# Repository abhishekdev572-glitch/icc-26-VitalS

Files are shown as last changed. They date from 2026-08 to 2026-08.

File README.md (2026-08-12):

# VitalSense Pressure Ulcer Prevention System

## Overview

VitalSense is an end-to-end pressure ulcer prevention system for bedridden patients. It combines an 8-sensor force-sensing resistor (FSR) array, inertial measurement unit (IMU), on-device machine learning inference, and real-time caregiver dashboards to continuously monitor posture, pressure distribution, and tissue injury risk across four anatomical zones (head, shoulders, hips, heels).

## System Architecture

```mermaid
graph TD
    subgraph Bed_Unit [Bedside Hardware]
        FSR[8× FSR Sensors\n74HC4051 MUX]
        ESP[ESP32-C3 Gateway\nBLE Peripheral + UDP Broadcaster]
        EFR[EFR32xG26 Node\nIMU + ML Inference + BLE Central]
    end

    subgraph Dashboards [Caregiver Interfaces]
        MOBILE[Flutter Mobile App\nUDP Listener]
        WEB[Web Kiosk Dashboard\nGTK4 + WebKit2]
    end

    FSR -->|ADC 0-4095| ESP
    ESP <-->|BLE GATT\nCommands 0x01/0x02/0x03| EFR
    EFR -->|IMU 60 Hz| EFR
    EFR -->|ML Risk 0-100| ESP
    ESP -->|UDP Broadcast\nPort 5005\nJSON v1| MOBILE
    ESP -->|UDP Broadcast\nPort 5005\nJSON v1| WEB

    style FSR fill:#e8f0fe,stroke:#1a73e8,stroke-width:2px,color:#1a73e8
    style ESP fill:#e6f4ea,stroke:#1e8e3e,stroke-width:2px,color:#1e8e3e
    style EFR fill:#fff3cd,stroke:#e67e22,stroke-width:2px,color:#e67e22
    style MOBILE fill:#fce4ec,stroke:#c2185b,stroke-width:2px,color:#c2185b
    style WEB fill:#f3e5f5,stroke:#7b1fa2,stroke-width:2px,color:#7b1fa2
```

## Hardware Requirements

| Component | Part Number | Quantity | Role |
|---|---|---|---|
| ESP32-C3 Development Board | ESP32-C3-DevKitM-1 / SuperMini | 1 | FSR acquisition, BLE peripheral, UDP broadcaster |
| EFR32xG26 Development Kit | BRD2608A (xG26) | 1 | IMU posture detection, ML inference, BLE central |
| Force Sensing Resistors | Interlink FSR 402 / equivalent | 8 | Pressure sensing at anatomical zones |
| Analog Multiplexer | 74HC4051 / CD4051 | 1 | 8-channel to single ADC |
| Inertial Measurement Unit | ICM-40627 (on xG26 board) | 1 | 6-axis motion, posture classification |
| Power Supply | 5V 2A USB-C | 2 | ESP32-C3 and EFR32xG26 power |

## Component Breakdown

| Component | Location | Technology Stack | Primary Responsibility |
|---|---|---|---|
| ESP32-C3 Firmware | `projects/Pipeline/ESP32 firmware/` | Arduino Core, NimBLE-Arduino 2.3.7 | 8-channel FSR acquisition via MUX, BLE GATT server, plate averaging, UDP JSON broadcast (1 Hz) |
| EFR32xG26 Firmware | `projects/Pipeline/EFR xG26 firmware/bt_imu_mode/` | C, Silicon Labs Gecko SDK 2026.6, TFLite Micro | IMU calibration (CENTER/LEFT/RIGHT), posture tracking at 60 Hz, BLE central connection to ESP32, ML inference, risk/state transmission |
| ML Model | `projects/Pipeline/model/` | PyTorch, ONNX, TensorFlow Lite | 380-parameter MLP (12→16→8→4), risk prediction 0-100 per zone, deployed as TFLite on EFR32 |
| Synthetic Dataset Kit | `projects/Pipeline/Synthetic dataset kit/` | Python, Pandas, PyTorch, scikit-learn | 60,000-sample synthetic dataset generation, teacher risk function, model training pipeline, ONNX/TFLite export |
| Mobile App | `projects/vitalsense-app/` | Flutter 3.x, Dart 3.x | UDP listener (port 5005), real-time gauges, posture duration, risk visualization, diagnostics panel |
| Web Dashboard | `projects/vitalsense-dashboard/` | Python 3.10+, GTK4, WebKit2GTK, React (JSX) | Kiosk-mode UDP receiver, HTTP frontend (port 8080), WebView display, SSE live updates |

## Communication Protocols

### BLE GATT (EFR32xG26 ↔ ESP32-C3)

| Parameter | Value |
|---|---|
| Target Device Name | `VitalSense-ESP32C3` |
| Service UUID | `7a0a0001-5b8a-4f4c-9d1d-8b4e3d7a1000` |
| RX Characteristic (EFR→ESP) | `7a0a0002-5b8a-4f4c-9d1d-8b4e3d7a1000` (Write w/ Response) |
| TX Characteristic (ESP→EFR) | `7a0a0003-5b8a-4f4c-9d1d-8b4e3d7a1000` (Notify) |

**Commands (EFR32 → ESP32):**

| Command | Payload | Description |
|---|---|---|
| `0x01` | (none) | Request fresh 8-FSR scan |
| `0x02` | `bodyId (1-4), risk (0-100), avoidFlag (0/1)` | ML risk update per body part |
| `0x03` | `pos, durationSec, riskValid, zoneId, score, level` | Posture + duration + summary state |

**Response (ESP32 → EFR32):**

| Byte | Value |
|---|---|
| `[0]` | `0x81` |
| `[1]` | `0x08` (sensor count) |
| `[2..17]` | 8 × `uint16_t` little-endian FSR values (ADC 0-4095) |

**Body IDs:**

| ID | Anatomical Zone |
|----|---|
| 1 | Head |
| 2 | Shoulders |
| 3 | Hips |
| 4 | Heels |

**Risk Levels:**

| Level | Value |
|---|---|
| LOW | 0 |
| MEDIUM | 1 |
| HIGH | 2 |

### UDP Broadcast (ESP32-C3 → Dashboards)

| Parameter | Value |
|---|---|
| Port | 5005 (broadcast to subnet) |
| Interval | 1000 ms |
| Format | JSON (manual `snprintf`, no ArduinoJson) |
| Protocol Version | 1 |

**Sample Payload:**

```json
{
  "protocol": 1,
  "deviceId": "VS-BED-001",
  "bed": 1,
  "position": "CENTER",
  "positionDuration": 45,
  "plates": {"head": 2048, "shoulders": 1892, "hips": 3120, "heels": 1567},
  "fsr": [2010, 2086, 1845, 1939, 3088, 3152, 1521, 1613],
  "riskValid": true,
  "risk": {"head": 12, "shoulders": 8, "hips": 45, "heels": 3},
  "highestRisk": {"zone": "HIPS", "score": 45, "level": "MEDIUM"},
  "avoidReturn": {"head": 0, "shoulders": 0, "hips": 0, "heels": 0},
  "uptime": 1234
}
```

**Field Reference:**

| Field | Type | Description |
|---|---|---|
| `protocol` | integer | Protocol version (1) |
| `deviceId` | string | Unique bed identifier |
| `bed` | integer | Bed number |
| `position` | string | `CENTER`, `LEFT`, `RIGHT`, `UNKNOWN` |
| `positionDuration` | integer | Uninterrupted seconds in current posture |
| `plates` | object | 4 averaged plate ADC values (0-4095) |
| `fsr` | array[8] | 8 raw FSR ADC values (0-4095) |
| `riskValid` | boolean | True after EFR32 threshold + all 4 risk packets |
| `risk` | object | Per-zone risk 0-100 (or -1 if invalid) |
| `highestRisk` | object | Zone with max risk + score + level |
| `avoidReturn` | object | Per-zone avoid flags (0/1) |
| `uptime` | integer | ESP32 uptime in seconds |

## Build & Setup Instructions

### ESP32-C3 Firmware

**Prerequisites:**
- Arduino IDE 2.x or VS Code + PlatformIO
- ESP32 Arduino Core 3.x
- NimBLE-Arduino library (Library Manager → "NimBLE-Arduino")

**Arduino IDE:**
1. Add board URL: `https://raw.githubusercontent.com/espressif/arduino-esp32/gh-pages/package_esp32_index.json`
2. Tools → Board → ESP32 Arduino → ESP32C3 Dev Module
3. Install library: Sketch → Include Library → Manage Libraries → NimBLE-Arduino
4. Open `VitalSense_ESP32.ino`
5. Configure WiFi credentials at top of file
6. Select port → Upload

**PlatformIO (`platformio.ini`):**
```ini
[env:esp32c3]
platform = espressif32
board = esp32c3-devkitm-1
framework = arduino
lib_deps = h2zero/NimBLE-Arduino@^2.3.7
monitor_speed = 115200
```

### EFR32xG26 Firmware

**Prerequisites:**
- Simplicity Studio 5 (v5.2+)
- Gecko SDK 2026.6.0
- BRD2608A (xG26 Dev Kit)

**Steps:**
1. File → Import → Silicon Labs → Project from SLCP
2. Select `bt_imu_mode.slcp`
3. Connect BRD2608A (power switch → AEM position)
4. Build (hammer icon)
5. Flash (debug icon)

**Post-Build (OTA DFU):**
```bash
commander gbl create output.gbl --app output.s37
```

**Pre-built Firmware:** Available at `bt_imu_mode/firmware file/bt_imu_mode.s37`

### ML Model Pipeline

**Prerequisites:**
```bash
pip install numpy pandas torch scikit-learn onnx onnxruntime tf2onnx
```

**Generate Dataset + Train:**
```bash
cd "projects/Pipeline/Synthetic dataset kit"
python build_pressure_risk_dataset.py
```

**Outputs:**
- `synthetic_pressure_ulcer_risk_dataset.csv` (60,000 rows)
- `pressure_risk_mlp.pt` (PyTorch state dict)
- `pressure_risk_model_metadata.json` (full provenance)

**Convert to TFLite (for EFR32):**
```bash
# Option 1: tf2onnx + tflite_convert
python -m tf2onnx.convert --input pressure_risk_mlp.onnx --output pressure_risk_mlp_tf.onnx
tflite_convert --output_file pressure_risk_mlp.tflite --input_file pressure_risk_mlp_tf.onnx

# Option 2: Silicon Labs AI/ML SDK (recommended)
# In Simplicity Studio: add "ML Model" component → select .tflite → auto-generates C++ wrapper
```

### Mobile App (Flutter)

**Prerequisites:**
- Flutter SDK >= 3.0.0
- Android SDK (for APK build)

```bash
cd projects/vitalsense-app
flutter pub get
flutter analyze
flutter run
```

**Production APK:**
```bash
flutter build apk --release
# Output: build/app/outputs/flutter-apk/app-release.apk
```

### Web Dashboard

```bash
cd projects/vitalsense-dashboard
python3 -m venv venv
source venv/bin/activate
# Ubuntu/Debian: sudo apt install python3-gi python3-gi-cairo gir1.2-gtk-4.0 gir1.2-webkit2-4.1
python app.py
```

## ADC Calibration & Model Specifications

### ADC Calibration (q05 / q95 per Zone)

Used for ADC → load normalization: `load = clip((adc - q05) / (q95 - q05), 0, 1)`

| Zone | q05 (Low Load) | q95 (High Load) |
|---|---|---|
| Head | 3119 | 3932 |
| Shoulders | 3537 | 3994 |
| Hips | 3007 | 3909 |
| Heels | 3222 | 4021 |

### Model Architecture

```
Input (12) → Linear(16) → ReLU → Linear(8) → ReLU → Linear(4) → Sigmoid
```

| Layer | Size |
|---|---|
| Input | 12 |
| Hidden 1 | 16 |
| Hidden 2 | 8 |
| Output | 4 |

**Parameters:** 380

### Model Inputs (12 Features, Fixed Order)

| Index | Feature | Description | Range |
|---|---|---|---|
| 0 | `position_CENTER` | One-hot posture | {0, 1} |
| 1 | `position_LEFT` | One-hot posture | {0, 1} |
| 2 | `position_RIGHT` | One-hot posture | {0, 1} |
| 3 | `log_duration_normalized` | `log1p(duration_sec) / log1p(7200)` | [0, 1] |
| 4 | `head_load` | Normalized pressure (ADC→load) | [0, 1] |
| 5 | `shoulders_load` | Normalized pressure | [0, 1] |
| 6 | `hips_load` | Normalized pressure | [0, 1] |
| 7 | `heels_load` | Normalized pressure | [0, 1] |
| 8 | `head_exposure_scaled` | Cumulative exposure (pressure × time) | [0, 1] |
| 9 | `shoulders_exposure_scaled` | Cumulative exposure | [0, 1] |
| 10 | `hips_exposure_scaled` | Cumulative exposure | [0, 1] |
| 11 | `heels_exposure_scaled` | Cumulative exposure | [0, 1] |

### Model Outputs (4)

| Index | Output | Description | Range |
|---|---|---|---|
| 0 | `head_risk_score_0_to_1` | Risk probability | [0, 1] |
| 1 | `shoulders_risk_score_0_to_1` | Risk probability | [0, 1] |
| 2 | `hips_risk_score_0_to_1` | Risk probability | [0, 1] |
| 3 | `heels_risk_score_0_to_1` | Risk probability | [0, 1] |

**Firmware scales to 0–100** for BLE transmission.

### Teacher Risk Function (Synthetic Labels)

```python
effective = clip((load - relief_floor) / (1.0 - relief_floor), 0, 1)
dose = effective^pressure_exponent * duration_sec / reference_duration_seconds
risk = 100 * (1 - exp(-risk_gain * dose))
```

| Parameter | Value |
|---|---|
| `reference_duration_seconds` | 7200 (2 hours) |
| `relief_floor` | 0.10 |
| `pressure_exponent` | 1.50 |
| `risk_gain` | 1.50 |
| `low_medium_threshold` | 35.0 |
| `medium_high_threshold` | 70.0 |

### Performance Metrics (Test Set: 12,000 rows, 24 subjects)

| Metric | Value |
|---|---|
| MAE (risk points 0–100) | 1.88 |
| RMSE (risk points 0–100) | 2.75 |
| Max Abs Error | 21.19 |
| Highest-risk body part accuracy | 90.2% |
| Highest-risk level (LOW/MED/HIGH) accuracy | 97.0% |

## Third-Party Libraries

| Library | Version | Location | Purpose |
|---|---|---|---|
| TensorFlow Lite Micro (TFLM) | 2.x | `projects/Pipeline/EFR xG26 firmware/bt_imu_mode/autogen/ml/third_party/tflm/` | On-device ML inference engine |
| FlatBuffers | 23.x | `.../flatbuffers/` | TFLite model serialization format |
| gemmlowp | — | `.../gemmlowp/` | Low-precision matrix multiplication for TFLM |
| ruy | — | `.../ruy/` | Matrix multiplication library for TFLM |
| NimBLE-Arduino | 2.3.7 | ESP32 firmware (PlatformIO/lib_deps) | Lightweight BLE stack for ESP32-C3 |

## Project Structure

```
icc-26-VitalS/
├── README.md                           # This file
├── LICENSE.md
├── .github/
│   ├── basic-ruleset.json
│   ├── CODEOWNERS
│   ├── CONTRIBUTING.md
│   └── workflows/
├── projects/
│   ├── README.md                       # Projects index
│   ├── vitalsense-app/                 # Flutter mobile app
│   │   ├── lib/
│   │   ├── android/
│   │   ├── pubspec.yaml
│   │   ├── README.md
│   │   └── VitalSense_Dashboard_Integration_Protocol_v1.md
│   ├── vitalsense-dashboard/           # Python GTK/WebKit kiosk
│   │   ├── app.py
│   │   ├── config.json
│   │   ├── backend/
│   │   ├── frontend/
│   │   ├── core/
│   │   ├── ui/
│   │   ├── assets/
│   │   └── README.md
│   └── Pipeline/
│       ├── ESP32 firmware/
│       │   ├── VitalSense_ESP32.ino
│       │   └── README.md
│       ├── EFR xG26 firmware/
│       │   ├── bt_imu_mode/            # Complete source project
│       │   │   ├── app.c / app.h
│       │   │   ├── main.c
│       │   │   ├── pressure_risk_ml_xg26.h/.cpp
│       │   │   ├── bt_imu_mode.slcp
│       │   │   ├── config/tflite/pressure_risk_mlp.tflite
│       │   │   ├── autogen/
│       │   │   ├── firmware file/bt_imu_mode.s37  # Pre-built .s37
│       │   │   └── README.md
│       │   └── firmware file/          # Pre-built firmware only
│       ├── model/
│       │   ├── pressure_risk_mlp.pt
│       │   ├── pressure_risk_mlp.onnx
│       │   ├── pressure_risk_mlp.tflite
│       │   ├── onnx_test_report.json
│       │   ├── onnx_test_predictions.csv
│       │   └── README.md
│       └── Synthetic dataset kit/
│           ├── build_pressure_risk_dataset.py
│           ├── pressure_risk_inference.py
│           ├── pressure_risk_model_metadata.json
│           ├── Pressure_Ulcer_Prevention_System_Project.md
│           └── README.md
```

## License

See [LICENSE.md](./LICENSE.md) for details.

## Contributing

Please follow the [CONTRIBUTING](./.github/CONTRIBUTING.md) guideline.

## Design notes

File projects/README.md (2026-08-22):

# VitalSense Projects

VitalSense is an end-to-end pressure-injury prevention system for monitoring bedridden patients. Sensor and posture data are processed on embedded hardware, broadcast over the local network, and presented to caregivers through mobile and web dashboards.

## System Overview

```text
8x FSR sensors --> ESP32-C3 <-- BLE --> EFR32xG26 (IMU + ML inference)
                     |
                     | VitalSense Protocol v1
                     | UDP JSON broadcast, port 5005, once per second
                     v
              Mobile app / Web dashboard

Android app -- temporary BLE connection --> ESP32-C3
              Wi-Fi provisioning only
```

The ESP32-C3 acquires pressure data, exchanges sensor and risk packets with the EFR32xG26, and broadcasts the combined telemetry. The Flutter app can provision the ESP32's Wi-Fi credentials over BLE; normal monitoring then continues over Wi-Fi and UDP.

## Repository Components

| Component | Path | Purpose |
|---|---|---|
| Engineering pipeline | [`Pipeline/`](./Pipeline/README.md) | ESP32 and EFR32 firmware, ML models, datasets, and training/export tools |
| ESP32-C3 firmware | [`Pipeline/ESP32 firmware/`](./Pipeline/ESP32%20firmware/README.md) | FSR acquisition, BLE services, Wi-Fi provisioning, and UDP broadcasting |
| Caregiver mobile app | [`vitalsense-app/`](./vitalsense-app/README.md) | Flutter Android dashboard, BLE device setup, live monitoring, and diagnostics |
| Web dashboard | [`vitalsense-dashboard/`](./vitalsense-dashboard/README.md) | Python/Flask monitoring dashboard |

## Mobile App v1.2.0

The latest documented app release is **v1.2.0**, released on **August 21, 2026**. It adds guided ESP32 Wi-Fi credential provisioning from the Android app.

Key additions include:

- BLE scanning and explicit VitalSense device selection with signal-strength labels.
- Wi-Fi SSID/password setup, including support for open networks.
- Detection of existing ESP32 credentials through the `STATUS` command.
- Options to keep, replace, or clear saved credentials.
- Live setup progress, strict response validation, timeouts, and recovery screens.
- End-to-end verification using a UDP packet from the selected ESP32's IP address.
- Android 12+ Bluetooth permissions and legacy Android BLE/location support.
- Password privacy protections: passwords are neither retained by the provider nor logged.

See the complete [v1.2.0 release notes](./vitalsense-app/RELEASE_NOTES_v1.2.0.md).

## ESP32 Wi-Fi Provisioning

App v1.2.0 requires ESP32 firmware that implements the VitalSense provisioning GATT service. The phone uses BLE only for setup; the ESP32 then joins Wi-Fi and sends monitoring data over UDP.

### Setup flow

1. Power on an ESP32 running compatible VitalSense firmware.
2. In the Android app, choose **Set Up VitalSense** or open **Settings > Device Connectivity**.
3. Allow the requested Bluetooth/Nearby Devices permission and select the intended unit.
4. Enter the Wi-Fi SSID and password, then start the connection.
5. Wait for the ESP32 to report its SSID and IP address.
6. Connect the phone to the same Wi-Fi network if needed.
7. Setup completes after the app receives a matching VitalSense UDP packet.

The app configures the ESP32 but does not switch the phone's Wi-Fi network.

### Provisioning contract

| Purpose | UUID |
|---|---|
| Service | `7a0a0101-5b8a-4f4c-9d1d-8b4e3d7a1000` |
| SSID write | `7a0a0102-5b8a-4f4c-9d1d-8b4e3d7a1000` |
| Password write | `7a0a0103-5b8a-4f4c-9d1d-8b4e3d7a1000` |
| Command write | `7a0a0104-5b8a-4f4c-9d1d-8b4e3d7a1000` |
| Status read/notify | `7a0a0105-5b8a-4f4c-9d1d-8b4e3d7a1000` |

Supported commands are `STATUS`, `CONNECT`, and `CLEAR`. For a new connection, the app writes the SSID, writes the password, and then sends `CONNECT`. Credentials are saved to ESP32 NVS only after the network connection succeeds.

For the complete BLE behavior, status values, and error handling, see the [app firmware contract](./vitalsense-app/README.md#esp32-firmware-contract) and [ESP32 firmware documentation](./Pipeline/ESP32%20firmware/README.md#wifi-provisioning-from-the-app-over-ble).

## Runtime Telemetry

After provisioning, the ESP32 broadcasts VitalSense Protocol v1 JSON to UDP port `5005` once per second. Packets include:

- Device and bed identifiers.
- Current posture and uninterrupted posture duration.
- Eight raw FSR readings and four anatomical plate averages.
- Per-zone risk for the Head, Shoulders, Hips, and Heels.
- Highest-risk zone, score, and level.
- Avoid-Return flags and device uptime.

The app reports the connection as `LIVE`, `STALE`, or `OFFLINE` based on incoming packet timestamps.

## Getting Started

### Mobile app

```bash
cd vitalsense-app
flutter pub get
flutter analyze
flutter test
flutter run
```

Build a release APK with:

```bash
flutter build apk --release
```

### ESP32 firmware

Open `Pipeline/ESP32 firmware/VitalSense_ESP32.ino` in Arduino IDE 2.x, select an ESP32-C3 board, install NimBLE-Arduino 2.x, and upload the sketch. Wi-Fi credentials are provisioned from the app and are not compiled into the firmware.

See the component READMEs for EFR32 firmware, ML pipeline, dashboard, hardware, and platform-specific setup details.

## Project Structure

```text
projects/
|-- Pipeline/
|   |-- ESP32 firmware/
|   |-- EFR xG26 firmware/
|   |-- model/
|   |-- Dataset/
|   `-- Synthetic dataset kit/
|-- vitalsense-app/
|-- vitalsense-dashboard/
`-- README.md
```

## License

VitalSense project content is licensed under the [Apache License 2.0](../LICENSE.md).

SPDX-License-Identifier: Apache-2.0

Individual components and bundled third-party libraries may have additional licenses; consult their documentation before redistribution.

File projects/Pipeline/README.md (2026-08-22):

# VitalSense Pipeline

## Overview

The Pipeline directory contains all firmware, machine learning models, dataset generation tools, and synthetic data for the VitalSense pressure ulcer prevention system. This is the core engineering pipeline that transforms raw sensor data into deployed on-device inference.

## Pipeline Components

| Component | Path | Description |
|---|---|---|
| **ESP32 Firmware** | `ESP32 firmware/` | FSR acquisition, BLE GATT server, UDP broadcaster (Arduino/NimBLE) |
| **EFR32xG26 Firmware** | `EFR xG26 firmware/` | IMU posture detection, TFLite Micro ML inference, BLE central (C/Silicon Labs SDK) |
| **ML Model** | `model/` | Trained model artifacts (PyTorch, ONNX, TFLite) with metadata and conversion scripts |
| **Synthetic Dataset Kit** | `Synthetic dataset kit/` | End-to-end pipeline: source alignment, synthetic generation, training, export |
| **Dataset** | `Dataset/` | Generated synthetic dataset (60K rows) and future generalization plan |

## Data Flow

```mermaid
graph TD
    subgraph Training_Pipeline [Offline Training Pipeline]
        SRC1[vitalsense_data_*.csv\nSmart Bedsheet FSR]
        SRC2[xg26_position_dataset*.csv\nSmart Belt IMU]
        SRC1 --> ALIGN[Align 1 Hz\nStable Segments]
        SRC2 --> ALIGN
        ALIGN --> CALIB[ADC Calibration\nq05/q95 per zone]
        CALIB --> SYNTH[Synthetic Generation\n120 subjects × 500 rows]
        SYNTH --> TEACHER[Teacher Risk Function\nPhysics-inspired labels]
        TEACHER --> TRAIN[Train MLP\n12→16→8→4, 380 params]
        TRAIN --> EXPORT[Export: .pt, .onnx, .tflite]
    end

    subgraph Deployment [On-Device Deployment]
        EXPORT --> TFLITE[pressure_risk_mlp.tflite]
        TFLITE --> SILABS[Silicon Labs AI/ML SDK]
        SILABS --> AUTOGEN[autogen/pressure_risk_mlp_generated.hpp]
        AUTOGEN --> WRAPPER[pressure_risk_ml_xg26.h/.cpp]
        WRAPPER --> EFR_FW[EFR32xG26 Firmware]
    end

    subgraph Runtime [Runtime Operation]
        EFR_FW -->|BLE Central| ESP_FW[ESP32 Firmware]
        ESP_FW -->|UDP Broadcast| DASH[Dashboards]
    end

    style SRC1 fill:#e8f0fe,stroke:#1a73e8,stroke-width:2px
    style SRC2 fill:#e8f0fe,stroke:#1a73e8,stroke-width:2px
    style TRAIN fill:#e6f4ea,stroke:#1e8e3e,stroke-width:2px
    style TFLITE fill:#fff3cd,stroke:#e67e22,stroke-width:2px
    style EFR_FW fill:#e6f4ea,stroke:#1e8e3e,stroke-width:2px
    style ESP_FW fill:#e8f0fe,stroke:#1a73e8,stroke-width:2px
```

## Component Details

### ESP32 Firmware (`ESP32 firmware/`)

**File:** `VitalSense_ESP32.ino` (single-file lean build)

| Aspect | Details |
|---|---|
| **MCU** | ESP32-C3 (DevKitM-1, SuperMini, etc.) |
| **BLE Stack** | NimBLE-Arduino 2.3.7 (lean, no Arduino BLE) |
| **JSON** | Manual `snprintf` (no ArduinoJson) |
| **ADC** | 12-bit, 8 channels via 74HC4051 MUX |
| **UDP** | Broadcast port 5005, 1 Hz, VitalSense Protocol v1 |
| **Role** | BLE Peripheral (GATT Server) |

**Key Responsibilities:**
- Read 8 FSR sensors via MUX (GPIO 0,2,3,4,5)
- Average pairs into 4 plates: Head, Shoulders, Hips, Heels
- BLE GATT Server: Service `7a0a0001-...`, RX `0x02`, TX `0x03`
- Respond to `0x01` with 18-byte FSR packet
- Receive risk packets `0x02` (×4) and state `0x03` from EFR32
- Broadcast complete JSON every 1 second

### EFR32xG26 Firmware (`EFR xG26 firmware/bt_imu_mode/`)

**Project:** `bt_imu_mode.slcp` (Simplicity Studio)

| Aspect | Details |
|---|---|
| **MCU** | EFR32MG26B510F3200IM68 (BRD2608A Dev Kit) |
| **SDK** | Gecko SDK 2026.6.0 |
| **IMU** | ICM-40627 (I²C, ~60 Hz) |
| **ML** | TensorFlow Lite Micro (Silicon Labs AI/ML SDK) |
| **BLE Role** | Central (scans for `VitalSense-ESP32C3`) |
| **Pre-built** | `firmware file/bt_imu_mode.s37` |

**Key Responsibilities:**
- Calibrate CENTER/LEFT/RIGHT postures via BTN0
- Classify posture at 60 Hz, track uninterrupted duration
- After 60s threshold: request FSR scan via `0x01` every 1s
- Decode 8 FSR values, compute 4 plate averages
- Run `pressure_risk_mlp` inference (5 inputs → 4 outputs)
- Send 4 risk packets `0x02` (bodyId, risk 0-100, avoidFlag)
- Send periodic state `0x03` (position, duration, risk summary)

**Button Mapping:**
- BTN0: Calibration sequence (CENTER→LEFT→RIGHT) / Restart calibration
- BTN1: Toggle Awake ↔ Standby

**RGB LED Status:**
- OFF: Standby
- YELLOW: Calibration required
- RED: IMU/ML/BLE error
- BLUE: Scanning
- PURPLE: Connecting/Discovering GATT
- CYAN: Link ready
- GREEN: Waiting for FSR response

### ML Model (`model/`)

**Architecture:**
```
Input (12) → Linear(16) → ReLU → Linear(8) → ReLU → Linear(4) → Sigmoid
```
**Parameters:** 380

**Files:**
| File | Format | Purpose |
|---|---|---|
| `pressure_risk_mlp.pt` | PyTorch | Training / fine-tuning / research |
| `pressure_risk_mlp.onnx` | ONNX | Cross-platform inference |
| `pressure_risk_mlp.tflite` | TensorFlow Lite | EFR32xG26 deployment (TFLite Micro) |
| `onnx_test_report.json` | JSON | ONNX vs PyTorch parity verification |
| `onnx_test_predictions.csv` | CSV | Sample predictions for regression testing |

**Inputs (12 features):**
| Index | Feature | Range |
|---|---|---|
| 0 | position_CENTER | {0,1} |
| 1 | position_LEFT | {0,1} |
| 2 | position_RIGHT | {0,1} |
| 3 | log_duration_normalized | [0,1] |
| 4 | head_load | [0,1] |
| 5 | shoulders_load | [0,1] |
| 6 | hips_load | [0,1] |
| 7 | heels_load | [0,1] |
| 8 | head_exposure_scaled | [0,1] |
| 9 | shoulders_exposure_scaled | [0,1] |
| 10 | hips_exposure_scaled | [0,1] |
| 11 | heels_exposure_scaled | [0,1] |

**Outputs (4):** Risk probability [0,1] for Head, Shoulders, Hips, Heels. Firmware scales to 0-100.

**EFR32 C API (5 inputs):**
```c
sl_status_t pressure_risk_ml_init(void);
sl_status_t pressure_risk_ml_predict(
    pressure_position_t position,  // 0=CENTER, 1=LEFT, 2=RIGHT
    uint32_t duration_sec,
    uint16_t head_adc,
    uint16_t shoulders_adc,
    uint16_t hips_adc,
    uint16_t heels_adc,
    pressure_risk_result_t *result);  // 4 scores 0-100
```

### Synthetic Dataset Kit (`Synthetic dataset kit/`)

**Pipeline Script:** `build_pressure_risk_dataset.py`

**Stages:**
1. **Align Sources** — Resample IMU (60 Hz) + FSR (1 Hz) to common 1 Hz timeline
2. **Extract Stable Segments** — Minimum 300s, 20s margin, posture-homogeneous
3. **ADC Calibration** — q05/q95 per zone from bedsheet recording
4. **Generate Synthetic Subjects** — 120 subjects × 500 rows = 60,000 total
   - Sample source stable row matching target posture
   - Apply subject/global/mattress variation (log-normal factors)
   - Add slow drift + measurement noise
   - Convert load → ADC via calibrated q05/q95
   - Compute teacher risk for sampled duration
5. **Train MLP** — PyTorch, subject-wise 80/20 split (96/24 subjects)
6. **Export** — .pt, .onnx, .tflite + metadata JSON

**Teacher Risk Function:**
```python
effective = clip((load - relief_floor) / (1.0 - relief_floor), 0, 1)
dose = effective^pressure_exponent * duration_sec / reference_duration_seconds
risk = 100 * (1 - exp(-risk_gain * dose))
```

| Parameter | Value |
|---|---|
| `reference_duration_seconds` | 7200 (2 hours) |
| `relief_floor` | 0.10 |
| `pressure_exponent` | 1.50 |
| `risk_gain` | 1.50 |
| `low_medium_threshold` | 35.0 |
| `medium_high_threshold` | 70.0 |

**Performance (Test: 12K rows, 24 subjects):**
| Metric | Value |
|---|---|
| MAE (0-100) | 1.88 |
| RMSE (0-100) | 2.75 |
| Max Abs Error | 21.19 |
| Highest-risk body part accuracy | 90.2% |
| Highest-risk level accuracy | 97.0% |

### Dataset (`Dataset/`)

| File | Size | Description |
|---|---|---|
| `synthetic_pressure_ulcer_risk_dataset.csv` | 18.8 MB | 60,000 rows, 120 subjects |
| `VitalSense_Future_Dataset_Generalization_Plan.md` | — | Roadmap for clinical data integration |

## ADC Calibration (q05 / q95)

Used for ADC → load normalization: `load = clip((adc - q05) / (q95 - q05), 0, 1)`

| Zone | q05 (Low Load) | q95 (High Load) |
|---|---|---|
| Head | 3119 | 3932 |
| Shoulders | 3537 | 3994 |
| Hips | 3007 | 3909 |
| Heels | 3222 | 4021 |

## Build Instructions

### ESP32 Firmware
```bash
# Arduino IDE: Open VitalSense_ESP32.ino, configure WiFi, upload
# PlatformIO:
cd "ESP32 firmware"
pio run -e esp32c3 -t upload
```

### EFR32xG26 Firmware
```bash
# Simplicity Studio 5:
# 1. File → Import → Silicon Labs → Project from SLCP
# 2. Select bt_imu_mode.slcp
# 3. Build (hammer) → Flash (debug)
# Post-build for OTA:
commander gbl create output.gbl --app output.s37
```

### ML Pipeline
```bash
cd "Synthetic dataset kit"
pip install numpy pandas torch scikit-learn onnx onnxruntime tf2onnx
python build_pressure_risk_dataset.py

# Convert to TFLite (for EFR32):
python -m tf2onnx.convert --input pressure_risk_mlp.onnx --output pressure_risk_mlp_tf.onnx
tflite_convert --output_file pressure_risk_mlp.tflite --input_file pressure_risk_mlp_tf.onnx
```

## Communication Protocols

### BLE GATT (EFR32 ↔ ESP32)

| Parameter | Value |
|---|---|
| Device Name | `VitalSense-ESP32C3` |
| Service UUID | `7a0a0001-5b8a-4f4c-9d1d-8b4e3d7a1000` |
| RX Char (EFR→ESP) | `7a0a0002-...` (Write w/ Response) |
| TX Char (ESP→EFR) | `7a0a0003-...` (Notify) |

**Commands (EFR→ESP):**
| CMD | Payload | Description |
|-----|---|---|
| `0x01` | — | Request 8-FSR scan |
| `0x02` | `bodyId, risk, avoidFlag` | Risk update (×4) |
| `0x03` | `pos, dur, valid, zone, score, level` | State summary |

**Response (ESP→EFR):** `0x81, 0x08, 8×uint16_le`

### UDP Broadcast (ESP32 → Dashboards)
- **Port:** 5005
- **Interval:** 1000 ms
- **Format:** JSON (VitalSense Protocol v1)

## Third-Party Libraries (EFR32)

| Library | Path | Purpose |
|---|---|---|
| TensorFlow Lite Micro | `bt_imu_mode/autogen/ml/third_party/tflm/` | On-device inference |
| FlatBuffers | `.../flatbuffers/` | Model serialization |
| gemmlowp | `.../gemmlowp/` | Low-precision GEMM |
| ruy | `.../ruy/` | Matrix multiplication |

## License

VitalSense project content is licensed under the [Apache License 2.0](../../LICENSE.md).

SPDX-License-Identifier: Apache-2.0  
Copyright 2025 VitalSense Project Contributors

Individual components may have additional licenses:
- EFR32 firmware: Zlib (Silicon Labs)
- Third-party libraries: Respective licenses

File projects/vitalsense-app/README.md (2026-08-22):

# VitalSense Caregiver Dashboard





**VitalSense** is a Flutter caregiver dashboard for monitoring bedridden patients. It receives real-time UDP telemetry from a VitalSense ESP32 gateway and displays posture, pressure-sensor data, pressure-injury risk, device status, and engineering diagnostics.

The app can also configure or change the ESP32 Wi-Fi credentials directly from an Android phone over Bluetooth Low Energy (BLE). BLE is used only during device setup; normal monitoring continues over local Wi-Fi and UDP.

## Features

- **ESP32 Wi-Fi setup over BLE**: Scan for a nearby VitalSense unit, select it, and send a Wi-Fi SSID and password from the app.
- **Credential management**: Detect an existing ESP32 Wi-Fi configuration, continue with it, replace it, or clear it from the device.
- **Provisioning feedback and recovery**: Show connection progress, validation errors, Bluetooth or permission issues, Wi-Fi failures, and retry actions.
- **End-to-end setup verification**: Confirm the ESP32-reported SSID and IP address, then wait for a matching VitalSense UDP packet before returning to live monitoring.
- **Automatic UDP discovery**: Listen on UDP port `5005` for VitalSense telemetry on the local Wi-Fi network.
- **Bed and connection monitoring**: Display `LIVE`, `STALE`, and `OFFLINE` states using packet timestamps and heartbeats.
- **Posture and duration tracking**: Display body orientation (`CENTER/BACK`, `LEFT`, or `RIGHT`) and posture duration.
- **Pressure-injury risk assessment**: Show risk gauges for the Head, Shoulders, Hips, and Heels, including the highest-risk zone.
- **Raw sensor data**: Visualize the eight-channel FSR array and four anatomical plate values.
- **Diagnostics**: Display ESP32 uptime, protocol version, source IP, raw ADC streams, Avoid-Return alerts, and provisioning status.

## Communication Architecture

```text
During setup

  Android phone  <-- temporary BLE GATT connection -->  ESP32
       |                                               receives SSID/password
       |                                               and joins Wi-Fi
       v
  waits for a matching UDP packet on port 5005

During monitoring

  [8x FSR Array]
         |
         v
  [ESP32 Gateway] <--- BLE ---> [EFR32xG26 MCU (IMU and ML inference)]
         |
         | UDP JSON broadcast on the local Wi-Fi network
         v
  [VitalSense Caregiver Dashboard]
```

The ESP32 provisioning connection is separate from the EFR32 telemetry BLE connection. The app accesses only the VitalSense Wi-Fi provisioning GATT service described below.

## Configure ESP32 Wi-Fi from the App

### Requirements

- An Android phone with Bluetooth Low Energy support.
- Bluetooth enabled while configuring the device.
- Nearby Devices permission on Android 12 or newer. Android 11 and older use Location permission for BLE scanning.
- A powered VitalSense ESP32 running firmware that implements the provisioning GATT contract in [ESP32 firmware contract](#esp32-firmware-contract).
- The Wi-Fi network name and password. Open networks are supported by leaving the password empty.

### Setup steps

1. Power on the VitalSense ESP32 and keep the phone nearby.
2. Open the app and use one of these entry points:
   - If no device is detected, wait for **Set Up VitalSense** to appear on the dashboard.
   - Open **Settings > Device Connectivity > Configure Device Wi-Fi** or **Change Wi-Fi Network**.
3. Allow Bluetooth/Nearby Devices access when prompted.
4. Select the correct VitalSense device from the scan results. Devices are shown with their BLE signal strength.
5. Enter the Wi-Fi network name and password, then tap **Connect to Wi-Fi**.
6. Keep the ESP32 powered while it joins the network. The app waits up to 45 seconds for the Wi-Fi result.
7. After the ESP32 reports its SSID and IP address, ensure the phone is connected to the same Wi-Fi network. The app disconnects the temporary BLE session and waits for live UDP data.
8. When a matching UDP packet arrives, setup completes and the dashboard opens. If data is not detected within 20 seconds, choose **Keep Listening** or **Configure Wi-Fi Again**.

The app configures the ESP32; it does not switch the phone to the selected Wi-Fi network.

### Existing credentials

When the selected ESP32 already reports a working Wi-Fi connection, the app shows the network name and device IP. You can:

- **Continue to Dashboard** without overwriting the stored credentials.
- **Change Wi-Fi** and submit another network.
- **Forget Device Wi-Fi** to send the `CLEAR` command and remove the ESP32 configuration.

### Credential handling

- The app sends the SSID and password only to the selected ESP32 over the active BLE connection.
- The password is not logged or retained by the provisioning provider.
- The password field is cleared immediately after the BLE write operation completes.
- The ESP32 firmware is responsible for securely storing, using, and clearing credentials on the device.

## ESP32 Firmware Contract

The ESP32 must expose the following BLE service and characteristics. UUID comparisons are case-insensitive.

| Purpose | UUID | App operation |
|---|---|---|
| Provisioning service | `7a0a0101-5b8a-4f4c-9d1d-8b4e3d7a1000` | Discover service |
| SSID | `7a0a0102-5b8a-4f4c-9d1d-8b4e3d7a1000` | Write UTF-8 SSID |
| Password | `7a0a0103-5b8a-4f4c-9d1d-8b4e3d7a1000` | Write UTF-8 password; may be empty |
| Command | `7a0a0104-5b8a-4f4c-9d1d-8b4e3d7a1000` | Write UTF-8 command |
| Status | `7a0a0105-5b8a-4f4c-9d1d-8b4e3d7a1000` | Enable notifications and receive UTF-8 status |

The SSID, password, and command characteristics must support BLE write or write-without-response. The status characteristic must support notifications.

### Device discovery

For reliable discovery, advertise the provisioning service UUID. The app also accepts devices whose BLE name is exactly `VitalSense` or starts with `VitalSense-` or `VS-`, then verifies that the required service and all four characteristics exist after connecting.

### Commands sent by the app

| Command | ESP32 behavior |
|---|---|
| `STATUS` | Report whether credentials exist and the current Wi-Fi state. Sent automatically after the app subscribes to status notifications. |
| `CONNECT` | Use the most recently written SSID and password to join Wi-Fi. |
| `CLEAR` | Remove stored Wi-Fi credentials and return the device to an unconfigured state. |

For a new connection, the app writes the SSID, writes the password, and then writes `CONNECT` in that order.

### Status notifications expected by the app

| Status payload | Meaning |
|---|---|
| `NO_CREDENTIALS` | No Wi-Fi credentials are stored. |
| `SSID_RECEIVED` | The SSID write was accepted. |
| `PASSWORD_RECEIVED` | The password write was accepted. |
| `CONNECTING\|<ssid>` | The ESP32 is attempting to join the network. |
| `CONNECTED\|<ssid>\|<ip-address>` | Wi-Fi joined successfully. The IP is also used to match the subsequent UDP packet. |
| `FAILED\|<reason>` | The connection failed. Use `CHECK_SSID_PASSWORD` to show the app's specific credential/signal guidance. |
| `DISCONNECTED\|<ssid>` | Credentials are known, but the ESP32 is not connected to Wi-Fi. |

Status fields must be present and non-empty where shown. Unknown or incomplete payloads are treated as malformed responses.

## Getting Started for Development

### Prerequisites

- [Flutter SDK](https://docs.flutter.dev/get-started/install) compatible with Dart `>=3.0.0 <4.0.0`
- Android SDK
- A compatible ESP32 for end-to-end BLE and UDP testing

### Install and run

```bash
flutter pub get
flutter analyze
flutter test
flutter run
```

### Build a release APK

```bash
flutter build apk --release
```

The APK is generated at `build/app/outputs/flutter-apk/app-release.apk`.

## UDP Telemetry Protocol

The dashboard implements **VitalSense Protocol v1** and listens on UDP port `5005` by default.

```json
{
  "protocol": 1,
  "deviceId": "VS-BED-01",
  "bed": 1,
  "position": "LEFT",
  "positionDuration": 1420,
  "plates": {
    "head": 120,
    "shoulders": 850,
    "hips": 2100,
    "heels": 430
  },
  "fsr": [100, 140, 800, 900, 2000, 2200, 400, 460],
  "riskValid": true,
  "risk": {
    "head": 15,
    "shoulders": 35,
    "hips": 82,
    "heels": 40
  },
  "highestRisk": {
    "zone": "HIPS",
    "score": 82,
    "level": "HIGH"
  },
  "avoidReturn": {
    "head": 0,
    "shoulders": 0,
    "hips": 1,
    "heels": 0
  },
  "uptime": 36400
}
```

See [VitalSense Dashboard Integration Protocol v1](VitalSense_Dashboard_Integration_Protocol_v1.md) for the full telemetry specification.

## Release Notes

- [v1.2.0 - ESP32 Wi-Fi Credential Provisioning](RELEASE_NOTES_v1.2.0.md)
- [v1.1.0](RELEASE_NOTES_v1.1.0.md)
- [v1.0.0](RELEASE_NOTES_v1.0.0.md)

## License

This project is licensed under the [Apache License 2.0](../../LICENSE.md).

SPDX-License-Identifier: Apache-2.0

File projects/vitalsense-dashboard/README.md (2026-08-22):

# VitalSense Web Dashboard

## Overview

The VitalSense Web Dashboard is a kiosk-mode application built with Python GTK4 and WebKit2GTK. It receives UDP broadcasts from the ESP32-C3 gateway on port 5005, serves a web-based frontend via an internal HTTP server, and displays real-time patient monitoring data in a full-screen WebView.

## System Architecture

```mermaid
graph TD
    A[ESP32-C3 Gateway] -->|UDP Broadcast\nPort 5005\nVitalSense Protocol v1| B[UDP Server\nbackend/udp_server.py]
    B --> C[Data Queue\nThread-Safe]
    C --> D[HTTP Frontend\npython -m http.server 8080]
    D --> E[Web Frontend\nfrontend/app.jsx]
    E --> F[WebKit2 WebView\nGTK4 Window]
    F --> G[Kiosk Display]

    style A fill:#e8f0fe,stroke:#1a73e8,stroke-width:2px,color:#1a73e8
    style B fill:#fff3cd,stroke:#e67e22,stroke-width:2px,color:#e67e22
    style C fill:#fce4ec,stroke:#c2185b,stroke-width:2px,color:#c2185b
    style D fill:#f3e5f5,stroke:#7b1fa2,stroke-width:2px,color:#7b1fa2
    style E fill:#e6f4ea,stroke:#1e8e3e,stroke-width:2px,color:#1e8e3e
    style F fill:#e8f0fe,stroke:#1a73e8,stroke-width:2px,color:#1a73e8
    style G fill:#e6f4ea,stroke:#1e8e3e,stroke-width:2px,color:#1e8e3e
```

## Components

| Component | Path | Description |
|---|---|---|
| Application Controller | `app.py` | Main entry point. Orchestrates splash screen, backend, frontend, and WebView lifecycle |
| UDP Server | `backend/udp_server.py` | Listens on 0.0.0.0:5005, parses VitalSense Protocol v1 JSON, pushes to thread-safe queue |
| HTTP Frontend | `frontend/` | Static assets served on port 8080. React-based UI (app.jsx) consuming data via SSE |
| Core Managers | `core/` | BackendManager, FrontendManager, ConfigManager - lifecycle and process management |
| UI Components | `ui/` | SplashScreen, potential AdminLogin/Settings windows |
| Assets | `assets/` | Icons, images, stylesheets |
| Configuration | `config.json` | Network, display, and application settings |

## Prerequisites

- Python 3.10 or higher
- GTK4 development libraries
- WebKit2GTK 4.1 development libraries
- Virtualenv (recommended)

### Ubuntu/Debian
```bash
sudo apt update
sudo apt install python3-gi python3-gi-cairo gir1.2-gtk-4.0 gir1.2-webkit2-4.1 python3-venv
```

### Fedora
```bash
sudo dnf install python3-gobject gtk4-devel webkit2gtk4.1-devel python3-virtualenv
```

## Configuration

Edit `config.json` before first run:

```json
{
  "udp_port": 5005,
  "http_port": 8080,
  "frontend_path": "frontend",
  "splash_duration_ms": 3000,
  "kiosk_mode": true,
  "log_level": "INFO"
}
```

| Field | Type | Default | Description |
|---|---|---|---|
| `udp_port` | integer | 5005 | UDP listen port for ESP32 broadcasts |
| `http_port` | integer | 8080 | HTTP server port for frontend |
| `frontend_path` | string | "frontend" | Relative path to static assets |
| `splash_duration_ms` | integer | 3000 | Splash screen display time |
| `kiosk_mode` | boolean | true | Full-screen, no window decorations |
| `log_level` | string | "INFO" | Logging verbosity |

## Installation & Execution

### 1. Create Virtual Environment
```bash
cd projects/vitalsense-dashboard
python3 -m venv venv
source venv/bin/activate
```

### 2. Install Python Dependencies
```bash
pip install --upgrade pip
# No additional PyPI packages required for core functionality
# Frontend uses React via CDN in app.jsx
```

### 3. Run Application
```bash
python app.py
```

### 4. Expected Startup Sequence
```
[INFO] Loading configuration from config.json
[INFO] Starting splash screen
[INFO] Starting backend UDP server on 0.0.0.0:5005
[INFO] Starting HTTP frontend on http://127.0.0.1:8080
[INFO] Waiting for frontend to respond...
[INFO] Frontend ready. Launching WebView.
[INFO] Application running in kiosk mode
```

## Protocol Support

The dashboard implements **VitalSense Protocol v1** over UDP:

- **Port:** 5005 (broadcast/subnet)
- **Format:** JSON, one packet per second
- **Key Fields:**
  - `deviceId`, `bed`, `position` (CENTER/LEFT/RIGHT)
  - `positionDuration` (seconds)
  - `plates`: {head, shoulders, hips, heels} ADC averages (0-4095)
  - `fsr`: 8 raw ADC values (0-4095)
  - `risk`: per-zone risk scores 0-100
  - `highestRisk`: {zone, score, level}
  - `avoidReturn`: per-zone flags

Refer to `../vitalsense-app/VitalSense_Dashboard_Integration_Protocol_v1.md` for complete specification.

## Frontend Data Flow

```
UDP Packet Received
        |
        v
Parse JSON -> Validate Schema
        |
        v
Thread-Safe Queue (maxsize=100)
        |
        v
SSE Endpoint (/events) <-- HTTP Server (port 8080)
        |
        v
Frontend (app.jsx) EventSource Connection
        |
        v
React State Update -> UI Re-render
```

## Project Structure

```
vitalsense-dashboard/
├── app.py                    # Main controller (1282 lines)
├── config.json               # Runtime configuration
├── backend/
│   └── udp_server.py         # UDP listener + parser
├── frontend/
│   ├── index.html            # Entry HTML
│   ├── app.jsx               # React application (JSX, babel standalone)
│   └── models/               # Data models / TypeScript interfaces
├── core/
│   ├── backend_manager.py    # Backend process lifecycle
│   ├── frontend_manager.py   # HTTP server lifecycle
│   └── config_manager.py     # Configuration loading
├── ui/
│   └── splash.py             # GTK SplashScreen
├── assets/
│   └── icons/                # Window icons, favicons
├── logs/                     # Rotating log files
└── README.md                 # This file
```

## Development Notes

### Adding New UI Screens
The `app.py` controller defines extension points in `_LIFECYCLE_TRANSITIONS`:
- `on_admin_login` -> `ui.login.AdminLoginWindow`
- `on_settings` -> `ui.settings.SettingsWindow`
- `on_kiosk_mode` -> Toggle full-screen
- `on_restart` / `on_shutdown` -> System integration

Implement the window class in `ui/` and register the factory in `_instantiate_*` methods.

### Logging
Logs written to `logs/vitalsense.log` with rotation (10MB, 5 backups). Console output at configured `log_level`.

### Testing Without Hardware
Run a mock UDP sender:
```bash
python3 -c "
import socket, json, time
sock = socket.socket(socket.AF_INET, socket.SOCK_DGRAM)
sock.setsockopt(socket.SOL_SOCKET, socket.SO_BROADCAST, 1)
packet = {
    'protocol': 1, 'deviceId': 'VS-TEST', 'bed': 1,
    'position': 'LEFT', 'positionDuration': 120,
    'plates': {'head': 2000, 'shoulders': 2500, 'hips': 3000, 'heels': 1800},
    'fsr': [1900,2100,2400,2600,2900,3100,1700,1900],
    'riskValid': True,
    'risk': {'head': 10, 'shoulders': 20, 'hips': 55, 'heels': 5},
    'highestRisk': {'zone': 'HIPS', 'score': 55, 'level': 'MEDIUM'},
    'avoidReturn': {'head': 0, 'shoulders': 0, 'hips': 0, 'heels': 0},
    'uptime': 3600
}
while True:
    sock.sendto(json.dumps(packet).encode(), ('255.255.255.255', 5005))
    time.sleep(1)
"
```

## License

This project is licensed under the [Apache License 2.0](../../LICENSE.md).

SPDX-License-Identifier: Apache-2.0  
Copyright 2025 VitalSense Project Contributors

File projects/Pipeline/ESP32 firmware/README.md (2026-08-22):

# VitalSense ESP32-C3 Firmware

**Build Type:** LEAN (NimBLE + Manual JSON, no ArduinoJson)

This firmware runs on the **ESP32-C3** and serves as the FSR sensor acquisition + BLE peripheral + Wi-Fi provisioning endpoint + UDP broadcaster in the VitalSense pressure ulcer prevention system. Wi-Fi credentials are supplied by the app over BLE, verified, and retained in ESP32 NVS; they are no longer compiled into the sketch.

---

## System Overview

```
┌─────────────────────────────────────────────────────────────────┐
│                     VITALSENSE SYSTEM                           │
├─────────────────────────────────────────────────────────────────┤
│                                                                 │
│  ┌──────────────┐      BLE (Peripheral)     ┌────────────────┐  │
│  │  EFR32xG26   │ ◄─────────────────────►   │   ESP32-C3     │  │
│  │  (Central)   │      GATT Server          │  (This FW)     │  │
│  └──────┬───────┘                           └───────┬────────┘  │
│         │                                           │            │
│         │                    8× FSR via 74HC4051    │            │
│         │                                           ▼            │
│         │  ┌─────────────────────────────────────────────────┐  │
│         │  │              UDP Broadcast (JSON)                │  │
│         │  │  Dashboard / App / Cloud ingestion               │  │
│         │  └─────────────────────────────────────────────────┘  │
│         │                                                       │
│         └───────────────────────────────────────────────────────│
│                                                                 │
└─────────────────────────────────────────────────────────────────┘
```

---

## ESP32-C3 Responsibilities

| # | Responsibility | Details |
|---|---|---|
| 1 | **FSR Acquisition** | Read 8 FSR sensors via 74HC4051/CD4051 MUX (12-bit ADC) |
| 2 | **Plate Averaging** | Average pairs → Head, Shoulders, Hips, Heels |
| 3 | **BLE Peripheral** | Advertise as `VitalSense-ESP32C3`, GATT server |
| 4 | **FSR Response** | On `0x01` command: fresh scan + notify 18-byte packet |
| 5 | **Risk RX** | Receive 4× `0x02` risk packets from EFR32 |
| 6 | **State RX** | Receive `0x03` posture+duration summary from EFR32 |
| 7 | **Wi-Fi Provisioning** | Receive, verify, and save Wi-Fi credentials from the app over BLE |
| 8 | **UDP Broadcast** | After Wi-Fi connects, send complete VitalSense Protocol v1 JSON every 1s |
| 9 | **Status LED** | GPIO 7 (active-low): solid = ready, blink = issues |

---

## Hardware

| Component | Pin | Notes |
|---|-----|---|
| MCU | ESP32-C3 | Any dev board (SuperMini, DevKitC-02, etc.) |
| MUX SIG | GPIO 0 | ADC1_CH0 (12-bit) |
| MUX S0 | GPIO 4 | Channel select bit 0 |
| MUX S1 | GPIO 3 | Channel select bit 1 |
| MUX S2 | GPIO 2 | Channel select bit 2 |
| MUX INH | GPIO 5 | Active-low enable (tie LOW) |
| Status LED | GPIO 7 | Active-low (LOW = ON) |
| FSR Sensors | 8× | Connected to MUX channels 0–7 |

### FSR → Plate Mapping

| Plate | FSR Channels | Average Of |
|---|---|---|
| Head | 0, 1 | `(FSR0 + FSR1) / 2` |
| Shoulders | 2, 3 | `(FSR2 + FSR3) / 2` |
| Hips | 4, 5 | `(FSR4 + FSR5) / 2` |
| Heels | 6, 7 | `(FSR6 + FSR7) / 2` |

---

## BLE Protocol

**Device Name:** `VitalSense-ESP32C3`  
**Service UUID:** `7a0a0001-5b8a-4f4c-9d1d-8b4e3d7a1000`  
**RX Char (EFR→ESP):** `7a0a0002-5b8a-4f4c-9d1d-8b4e3d7a1000` (WRITE)  
**TX Char (ESP→EFR):** `7a0a0003-5b8a-4f4c-9d1d-8b4e3d7a1000` (READ | NOTIFY)

### Commands (EFR32 → ESP32)

| CMD | Payload | Description |
|-----|---|---|
| `0x01` | — | Request fresh 8-FSR scan |
| `0x02` | `bodyId, risk(0-100), avoidFlag` | ML risk per body (×4) |
| `0x03` | `pos, dur_u32_le, riskValid, zone, score, level` | Posture summary |

### Response (ESP32 → EFR32)

| Byte | Value |
|---|---|
| `[0]` | `0x81` |
| `[1]` | `0x08` (sensor count) |
| `[2..17]` | 8 × `uint16_t` little-endian FSR values |

### Body IDs (for `0x02`)

| ID | Body Part |
|----|---|
| 1 | Head |
| 2 | Shoulders |
| 3 | Hips |
| 4 | Heels |

### State Packet (`0x03`) — 10 bytes

| Offset | Field | Description |
|---|---|---|
| `[0]` | `0x03` | Command |
| `[1]` | position | 0=CENTER, 1=LEFT, 2=RIGHT |
| `[2..5]` | duration_sec | uint32 little-endian |
| `[6]` | risk_valid | 0/1 |
| `[7]` | highest_zone | 0=none, 1=Head, 2=Shoulders, 3=Hips, 4=Heels |
| `[8]` | highest_score | 0–100 |
| `[9]` | risk_level | 0=LOW, 1=MEDIUM, 2=HIGH |

---

## Wi-Fi Provisioning from the App over BLE

The phone connects to the same BLE device name, `VitalSense-ESP32C3`, then discovers the Wi-Fi provisioning service. Only the main VitalSense service UUID is included in the advertising packet, so the app must perform GATT service discovery after connecting instead of filtering for the provisioning UUID in advertisements.

The ESP32 continues advertising while one client is connected (up to two clients), allowing the phone and EFR32xG26 to be connected at the same time.

### Provisioning GATT Service

| Item | UUID | Properties | App value |
|---|---|---|---|
| Service | `7a0a0101-5b8a-4f4c-9d1d-8b4e3d7a1000` | - | Wi-Fi provisioning service |
| SSID | `7a0a0102-5b8a-4f4c-9d1d-8b4e3d7a1000` | WRITE | UTF-8 SSID, 1-32 bytes |
| Password | `7a0a0103-5b8a-4f4c-9d1d-8b4e3d7a1000` | WRITE | UTF-8 password, up to 64 bytes |
| Command | `7a0a0104-5b8a-4f4c-9d1d-8b4e3d7a1000` | WRITE | UTF-8 command: `CONNECT`, `STATUS`, or `CLEAR` |
| Status | `7a0a0105-5b8a-4f4c-9d1d-8b4e3d7a1000` | READ, NOTIFY | UTF-8 provisioning state/result |

For WPA/WPA2, the password must be 8-64 bytes. The password characteristic must still be written before `CONNECT`; an empty value represents an open network.

### App Provisioning Sequence

1. Scan for and connect to BLE device `VitalSense-ESP32C3`.
2. Discover the provisioning service and subscribe to notifications on the Status characteristic.
3. Write the SSID to the SSID characteristic and wait for `SSID_RECEIVED`.
4. Write the password to the Password characteristic and wait for `PASSWORD_RECEIVED`.
5. Write `CONNECT` to the Command characteristic.
6. The ESP32 reports `CONNECTING|<ssid>` and tests the candidate network for up to 20 seconds.
7. On success, the ESP32 reports `CONNECTED|<ssid>|<ip>`, saves the verified credentials in NVS, opens UDP port 5005, and begins the normal one-second UDP broadcast cycle.
8. On failure, it reports `FAILED|CHECK_SSID_PASSWORD`. Existing saved credentials are not replaced, and the ESP32 reconnects with the last known-good credentials when available.

Credential writes are staged in RAM. They become the active saved credentials only after `CONNECT` succeeds. On later boots, BLE starts first and the ESP32 automatically connects with the saved NVS credentials. If no valid credentials exist, it remains available over BLE and reports `NO_CREDENTIALS` until the app provisions it.

### Commands and Status Values

| Command | Behavior |
|---|---|
| `CONNECT` | Validate and test the staged SSID/password, then save them only after a successful connection |
| `STATUS` | Notify the current state: `CONNECTED|<ssid>|<ip>`, `CONNECTING|<ssid>`, `DISCONNECTED|<ssid>`, or `NO_CREDENTIALS` |
| `CLEAR` | Erase saved and staged credentials, disconnect Wi-Fi, stop UDP, and report `CLEARED` |

Other status/error values include `BOOTING`, `CONNECTING_SAVED`, `ERROR|SSID_EMPTY`, `ERROR|SSID_TOO_LONG`, `ERROR|PASSWORD_TOO_LONG`, `ERROR|SEND_SSID_AND_PASSWORD`, `ERROR|INVALID_CREDENTIALS_FORMAT`, `ERROR|NVS_SAVE_FAILED`, `ERROR|BAD_COMMAND`, and `ERROR|UNKNOWN_COMMAND`.

### Transition to Data Transmission

Provisioning and data transmission use different links:

1. The app supplies network credentials over BLE.
2. The ESP32 joins that Wi-Fi network in station mode and determines the subnet broadcast address.
3. UDP is initialized on port 5005 after the connection succeeds.
4. VitalSense Protocol v1 JSON is broadcast once per second to the subnet while Wi-Fi remains connected.
5. If Wi-Fi drops, UDP stops and the ESP32 retries the saved network every 5 seconds. Transmission resumes automatically after reconnection.

The EFR32 BLE sensor/risk exchange continues independently. The status LED becomes solid only after Wi-Fi is connected, the EFR32 link has been identified by a valid protocol write, and at least one UDP packet has transmitted successfully.

---

## UDP Broadcast (VitalSense Protocol v1)

**Port:** 5005 (broadcast to subnet)  
**Interval:** 1000 ms  
**Format:** Manual JSON (no ArduinoJson)

```json
{
  "protocol": 1,
  "deviceId": "VS-BED-001",
  "bed": 1,
  "position": "CENTER",
  "positionDuration": 45,
  "plates": {"head": 2048, "shoulders": 1892, "hips": 3120, "heels": 1567},
  "fsr": [2010, 2086, 1845, 1939, 3088, 3152, 1521, 1613],
  "riskValid": true,
  "risk": {"head": 12, "shoulders": 8, "hips": 45, "heels": 3},
  "highestRisk": {"zone": "HIPS", "score": 45, "level": "MEDIUM"},
  "avoidReturn": {"head": 0, "shoulders": 0, "hips": 0, "heels": 0},
  "uptime": 1234
}
```

### Field Notes

| Field | Description |
|---|---|
| `position` | `"CENTER"`, `"LEFT"`, `"RIGHT"`, `"UNKNOWN"` |
| `positionDuration` | Uninterrupted seconds in current posture |
| `plates` | 4 averaged plate ADC values (0–4095) |
| `fsr` | 8 raw FSR ADC values (0–4095) |
| `riskValid` | `true` only after EFR32 threshold + all 4 risk packets |
| `risk` | Per-body risk 0–100 (or `-1` if not valid) |
| `highestRisk` | Zone with max risk + score + level |
| `avoidReturn` | Per-body flag (0/1) from EFR32 `0x02` packets |
| `uptime` | ESP32 uptime in seconds |

---

## Status LED (GPIO 7, Active-Low)

| Pattern | Meaning |
|---|---|
| **Solid ON** | Wi-Fi connected + BLE connected + UDP transmitted |
| **Blinking (500 ms)** | Any of: Wi-Fi down, BLE disconnected, no UDP success yet |
| **OFF** | Never (LED only OFF during solid ON state) |

> **Electrical:** GPIO LOW = LED ON, GPIO HIGH = LED OFF

---

## Key Timing Constants

| Constant | Value | Description |
|---|---|---|
| `SENSOR_SCAN_INTERVAL_MS` | 250 | Periodic FSR scan for local freshness |
| `UDP_SEND_INTERVAL_MS` | 1000 | UDP broadcast interval |
| `WIFI_RETRY_INTERVAL_MS` | 5000 | Wi-Fi reconnect retry |
| `WIFI_PROVISION_TIMEOUT_MS` | 20000 | Time allowed to verify credentials received over BLE |
| `MUX_SETTLE_MS` | 3 | MUX channel settle time |
| `SAMPLES_PER_READ` | 8 | ADC samples per channel (averaged) |
| `SAMPLE_DELAY_MS` | 1 | Delay between samples |

---

## User Configuration

Wi-Fi credentials are not configured in the source file. Provision them from the app through the BLE service described above. The following deployment and network values remain configurable at the top of `VitalSense_ESP32.ino`:

```cpp
static const uint16_t UDP_PORT = 5005;

static const uint8_t PROTOCOL_VERSION = 1;
static const char* DEVICE_ID = "VS-BED-001";
static const uint8_t BED_ID = 1;
```

---

## Building & Flashing

### Prerequisites

- **Arduino IDE** 2.x or **VS Code + PlatformIO**
- **ESP32 Arduino Core** 3.x
- **NimBLE-Arduino** library (Library Manager → search "NimBLE-Arduino")

### Arduino IDE

1. Install ESP32 board package:  
   `File → Preferences → Additional Boards Manager URLs:`  
   `https://raw.githubusercontent.com/espressif/arduino-esp32/gh-pages/package_esp32_index.json`
2. `Tools → Board → ESP32 Arduino → ESP32C3 Dev Module` (or your board)
3. Install library: `Sketch → Include Library → Manage Libraries → NimBLE-Arduino`
4. Open `VitalSense_ESP32.ino`
5. Select port, click **Upload**

### PlatformIO (`platformio.ini`)

```ini
[env:esp32c3]
platform = espressif32
board = esp32c3-devkitm-1  ; or your board
framework = arduino
lib_deps =
    h2zero/NimBLE-Arduino@^2.3.7
monitor_speed = 115200
```

---

## Serial Debug Output (115200 baud)

```
[WiFi] No valid saved credentials
[BLE] Wi-Fi provisioning service: OK
[BLE] Service start: OK
[BLE] Server start: CALLED
[BLE] Local GATT service check: FOUND
[BLE] VitalSense peripheral + Wi-Fi provisioning ready
[WiFi] Waiting for BLE provisioning
[WiFi Prov] NO_CREDENTIALS
[BOOT] VitalSense LEAN ready
[WiFi Prov] SSID_RECEIVED
[WiFi Prov] PASSWORD_RECEIVED
[WiFi Prov] CONNECTING|Hospital-WiFi
[WiFi Prov] CONNECTED|Hospital-WiFi|192.168.1.42
[WiFi Prov] Credentials verified and saved
[WiFi] IP=192.168.1.42
[UDP] Broadcast=192.168.1.255:5005
[BLE] EFR32 connected
[BLE TX] FSR 2010,2086,1845,1939,3088,3152,1521,1613
[BLE] EFR32 disconnected
[BLE] EFR32 connected
```

---

## Project Structure

```
ESP32 firmware/
└── VitalSense_ESP32.ino    # Single-file sketch (lean build)
```

### Lean Build Optimizations

| Removed | Replaced With |
|---|---|
| Arduino BLE (large) | NimBLE-Arduino 2.x |
| ArduinoJson | Manual `snprintf` JSON |
| Local ML / pressure algorithm | EFR32 does all inference |
| Movement / duration tracking | EFR32 tracks posture time |
| BLE2902 CCCD object | NimBLE auto-creates |

---

## Protocol Compatibility

| EFR32 Firmware | ESP32 Firmware | Protocol |
|---|---|---|
| `VITALSENSE_XG26_IMU_BLE_ML_V1` | This lean build | v1 |

---

## References

- [NimBLE-Arduino GitHub](https://github.com/h2zero/NimBLE-Arduino)
- [ESP32-C3 Technical Reference](https://www.espressif.com/en/products/socs/esp32-c3)
- [74HC4051 Datasheet](https://www.nxp.com/docs/en/data-sheet/74HC_HCT4051.pdf)
- VitalSense Protocol v1 (this document)

---

## License

This project is licensed under the [Apache License 2.0](../../../LICENSE.md).

SPDX-License-Identifier: Apache-2.0  
Copyright 2025 VitalSense Project Contributors

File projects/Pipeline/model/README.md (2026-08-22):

# VitalSense Pressure Risk ML Model

> **Status:** Engineering prototype / synthetic teacher model  
> **Target deployment:** Silicon Labs EFR32xG26  
> **Model family:** Small MLP for embedded pressure-risk inference  
> **Last README revision:** 2026-08-13

This folder contains the VitalSense `pressure_risk_mlp` model and deployment artifacts.

The model is designed to estimate a **normalized engineering pressure-risk score** for four body regions:

- Head
- Shoulders
- Hips
- Heels

The current model is trained primarily on **synthetic labels generated by an engineering teacher function**. It is **not a clinically validated pressure-ulcer probability model**.

---

# 1. Model Files

| File | Format | Purpose |
|---|---|---|
| `pressure_risk_mlp.pt` | PyTorch | Training / fine-tuning / research |
| `pressure_risk_mlp.onnx` | ONNX | Cross-platform inference and model interchange |
| `pressure_risk_mlp.tflite` | TensorFlow Lite / LiteRT | EFR32xG26 deployment |
| `onnx_test_report.json` | JSON | ONNX vs PyTorch parity verification |
| `onnx_test_predictions.csv` | CSV | Sample predictions for regression testing |

For EFR32xG26 deployment, the `.tflite` model is integrated into the Silicon Labs AI/ML project and compiled into generated model artifacts.

> **Important:** Exact generated filenames depend on the Silicon Labs AI/ML SDK version and the ML Model component instance name.

---

# 2. Model Architecture

```text
Input (12)
   ↓
Dense(16, ReLU)
   ↓
Dense(8, ReLU)
   ↓
Dense(4, Sigmoid)
```

**Parameter count:** 380

**Training framework:** PyTorch

**Deployment path:**

```text
PyTorch
   ↓
ONNX
   ↓
TFLite / LiteRT
   ↓
Silicon Labs AI/ML SDK
   ↓
EFR32xG26
```

---

# 3. Model Inputs

The neural network receives **12 features in a fixed order**.

| Index | Feature | Description | Expected Range |
|---|---|---|---|
| 0 | `position_CENTER` | CENTER posture one-hot | {0, 1} |
| 1 | `position_LEFT` | LEFT posture one-hot | {0, 1} |
| 2 | `position_RIGHT` | RIGHT posture one-hot | {0, 1} |
| 3 | `log_duration_normalized` | Log-scaled same-position duration | approximately [0, 1] for 0–7200 s |
| 4 | `head_load` | Normalized head pressure | [0, 1] |
| 5 | `shoulders_load` | Normalized shoulder pressure | [0, 1] |
| 6 | `hips_load` | Normalized hip pressure | [0, 1] |
| 7 | `heels_load` | Normalized heel pressure | [0, 1] |
| 8 | `head_exposure_scaled` | Head pressure-duration exposure feature | [0, 1] |
| 9 | `shoulders_exposure_scaled` | Shoulder pressure-duration exposure feature | [0, 1] |
| 10 | `hips_exposure_scaled` | Hip pressure-duration exposure feature | [0, 1] |
| 11 | `heels_exposure_scaled` | Heel pressure-duration exposure feature | [0, 1] |

## Duration preprocessing

The documented duration feature is:

```python
log_duration_normalized = (
    np.log1p(duration_sec)
    / np.log1p(7200.0)
)
```

If durations greater than 7200 seconds are accepted by production firmware, the intended clipping or extrapolation behavior must be explicitly defined and kept identical between training and firmware.

---

# 4. Firmware-Facing Inputs

The firmware wrapper does **not** require the caller to provide all 12 neural-network features.

The application-facing wrapper accepts **six logical inputs**:

1. `position`
2. `duration_sec`
3. `head_adc`
4. `shoulders_adc`
5. `hips_adc`
6. `heels_adc`

The wrapper is responsible for generating the 12 model features before inference.

Example API:

```c
sl_status_t pressure_risk_ml_predict(
    pressure_position_t position,
    uint32_t duration_sec,
    uint16_t head_adc,
    uint16_t shoulders_adc,
    uint16_t hips_adc,
    uint16_t heels_adc,
    pressure_risk_result_t *result
);
```

> Previous documentation incorrectly referred to this as a five-input API. It is six logical inputs plus the output/result pointer.

---

# 5. Model Outputs

The network produces four sigmoid outputs:

| Index | Output | Meaning | Range |
|---|---|---|---|
| 0 | `head_risk_score_0_to_1` | Head engineering risk score | [0, 1] |
| 1 | `shoulders_risk_score_0_to_1` | Shoulder engineering risk score | [0, 1] |
| 2 | `hips_risk_score_0_to_1` | Hip engineering risk score | [0, 1] |
| 3 | `heels_risk_score_0_to_1` | Heel engineering risk score | [0, 1] |

For BLE/application reporting, firmware may scale these values to:

```text
0–100 risk points
```

## Terminology

Do **not** describe these values as clinical probabilities.

Preferred terminology:

```text
engineering risk score
normalized risk score
pressure-risk index
```

Avoid:

```text
pressure-ulcer probability
clinical probability
diagnostic probability
```

unless clinical validation is performed in the future.

---

# 6. Synthetic Teacher Model

The current labels are generated from a physics-inspired / engineering risk function.

The documented teacher relationship is:

```python
risk_zone = (
    risk_gain
    * (pressure ** pressure_exponent)
    * np.log1p(duration_sec / reference_duration_seconds)
)

risk_zone = max(risk_zone, relief_floor)
```

Current parameters:

| Parameter | Value |
|---|---:|
| `reference_duration_seconds` | 7200 |
| `relief_floor` | 0.1 |
| `pressure_exponent` | 1.5 |
| `risk_gain` | 1.5 |
| `low_medium_threshold` | 35.0 |
| `medium_high_threshold` | 70.0 |

## Critical target-range requirement

The neural-network output uses a sigmoid and is therefore restricted to:

```text
0 ≤ model_output ≤ 1
```

However, the documented teacher equation can exceed `1.0`.

For example:

```text
pressure = 1.0
duration = 7200 sec

1.5 × 1.0^1.5 × log(2)
≈ 1.0397
```

Therefore, the **training target must have a clearly defined range**.

For future retraining, use an explicit clamp such as:

```python
risk_zone = (
    risk_gain
    * (pressure ** pressure_exponent)
    * np.log1p(duration_sec / reference_duration_seconds)
)

risk_zone = max(risk_zone, relief_floor)
risk_zone = np.clip(risk_zone, 0.0, 1.0)
```

> **Verification required for the existing trained model:** Check the actual training script to confirm whether clipping to `[0,1]` was already applied. The previous README did not document this. Do not assume the current `.pt` model was trained with clipping until the training code is verified.

---

# 7. Risk Levels

Risk level thresholds are applied to the **0–100 engineering risk score**.

```text
LOW     : score < 35
MEDIUM  : 35 ≤ score < 70
HIGH    : score ≥ 70
```

Current thresholds:

| Transition | Threshold |
|---|---:|
| LOW → MEDIUM | 35 |
| MEDIUM → HIGH | 70 |

These are **engineering thresholds**, not clinical diagnostic thresholds.

Any future threshold change must be versioned together with:

- dataset version
- teacher-model version
- preprocessing version
- trained-model version
- firmware version

---

# 8. Posture Load Means

The currently documented posture load means from the original recording are:

| Posture | Head | Shoulders | Hips | Heels |
|---|---:|---:|---:|---:|
| CENTER | 0.754 | 0.755 | 0.689 | 0.843 |
| LEFT | 0.831 | 0.253 | 0.925 | 0.247 |
| RIGHT | 0.543 | 0.890 | 0.251 | 0.431 |

These values characterize the current data-generation setup.

They must **not be assumed to represent the complete target population**.

Future real-subject data should test whether these distributions remain representative across:

- body weight
- height
- body composition
- mattress
- clothing
- session/day
- sensor mat
- sensor positioning
- CENTER / LEFT / RIGHT posture

---

# 9. ADC → Load Calibration

Current regional ADC normalization:

| Region | q05 | q95 |
|---|---:|---:|
| Head | 3119 | 3932 |
| Shoulders | 3537 | 3994 |
| Hips | 3007 | 3909 |
| Heels | 3222 | 4021 |

Current normalization:

```python
load = np.clip(
    (adc - q05) / (q95 - q05),
    0.0,
    1.0
)
```

## Calibration warning

These q05/q95 constants are a major part of the inference pipeline.

If they were derived from a limited number of people, sessions, mattresses, or physical sensor mats, they may not generalize to new subjects or hardware.

A future population study should compare:

```text
A. global per-region normalization
B. baseline-corrected normalization
C. sensor-mat-specific normalization
D. population percentile normalization
E. learned normalization
F. combinations of the above
```

Do not calculate future q05/q95 calibration statistics from the full dataset before the train/validation/test split.

Correct process:

```text
split by subject
      ↓
fit calibration / normalization using TRAIN subjects only
      ↓
freeze calibration
      ↓
apply exactly the same calibration to VALIDATION and TEST
```

---

# 10. Exposure Features

The model currently uses four exposure features:

```text
head_exposure_scaled
shoulders_exposure_scaled
hips_exposure_scaled
heels_exposure_scaled
```

The previous README did not define the exact mathematical formula used to calculate these features.

This is a reproducibility risk.

Before the next training release, document the exact implementation used by the training code, including:

```text
input load
input duration
scaling constant
clipping behavior
maximum duration behavior
numeric precision
```

The training implementation and firmware implementation must be mathematically equivalent.

Example documentation format:

```python
# Replace this placeholder with the exact formula from the training code.
exposure_scaled = EXACT_TRAINING_FORMULA(load, duration_sec)
```

Do **not** invent or approximate the exposure formula from the feature name.

---

# 11. Dataset

Current documented sources:

| Source | Rows / Subjects | Documented Role |
|---|---:|---|
| Stable 1-second recordings | 1,735 rows | Real recorded source data / characterization |
| Synthetic augmentation | 60,000 rows | Synthetic model dataset |
| Current training partition | 48,000 rows / 96 synthetic subjects | Model training |
| Current test partition | 12,000 rows / 24 synthetic subjects | Model evaluation |

The current 48,000 + 12,000 split accounts for the 60,000 synthetic rows.

## Dataset provenance item to verify

The previous documentation lists the 1,735 stable recordings separately from the 60,000 synthetic rows, but does not fully document whether the stable rows were:

- used only for calibration / synthetic-distribution estimation,
- included directly in training,
- used for validation,
- or held out independently.

Before the next model release, the training code and dataset manifest should explicitly document this.

---

# 12. Current Model Split

The currently reported model used:

```text
96 synthetic subjects → training
24 synthetic subjects → test
```

The split is subject-wise, which is preferable to randomly splitting individual rows.

This helps prevent samples from the same synthetic subject appearing in both training and test sets.

However, the current evaluation contains **no independently documented validation population**.

Therefore, the current test results should be treated as evaluation of the existing synthetic-model pipeline, not as final evidence of production or human generalization.

---

# 13. Current Performance

Current documented test set:

```text
12,000 rows
24 synthetic subjects
```

Current metrics:

| Metric | Value |
|---|---:|
| MAE, risk points 0–100 | 1.88 |
| RMSE, risk points 0–100 | 2.75 |
| Maximum absolute error | 21.19 |
| Highest-risk body-part accuracy | 90.2% |
| Highest-risk level accuracy | 97.0% |

## Interpretation

The average error is low for imitation of the synthetic engineering teacher.

However, the following require additional analysis:

### Maximum error

A maximum absolute error of `21.19` risk points is materially larger than the average error.

The error report should identify:

- body region
- posture
- duration
- normalized load
- risk level
- subject
- proximity to clipping
- proximity to the 35/70 thresholds

### Highest-risk body-part accuracy

A body-part accuracy of `90.2%` should be interpreted together with the score margin between the highest and second-highest regions.

Example:

```text
Teacher:
Head = 54
Hips = 53

Model:
Head = 52
Hips = 53
```

The body-part classification changes even though the numerical error is small.

For future reports calculate:

```python
risk_margin = highest_risk_score - second_highest_risk_score
```

and report highest-risk-body-part accuracy by margin band:

```text
< 2 points
2–5 points
5–10 points
> 10 points
```

---

# 14. Required Retraining Split

For the next model version, use a three-way **subject-wise** split:

```text
70% subjects → TRAIN
15% subjects → VALIDATION
15% subjects → TEST
```

Example:

```text
TRAIN
-----
fit calibration
fit normalization
train model weights

VALIDATION
----------
feature selection
architecture selection
learning-rate selection
epoch selection
threshold tuning
teacher-model tuning if required

TEST
----
final frozen evaluation only
```

A subject must appear in only one partition.

Never randomly mix rows from the same subject across train, validation, and test.

---

# 15. Data Leakage Prevention

The following operations must be performed using **training subjects only**:

- q05/q95 calculation
- normalization statistics
- synthetic-distribution fitting if derived from real subjects
- feature scaling
- threshold optimization
- hyperparameter selection

Correct workflow:

```text
subject split
    ↓
TRAIN statistics
    ↓
freeze preprocessing
    ↓
apply frozen preprocessing to VALIDATION
    ↓
apply frozen preprocessing to TEST
```

The final test population should remain untouched until the model design is frozen.

---

# 16. Recommended Evaluation Metrics

Do not evaluate only overall MAE.

For each model release, report:

```text
MAE
RMSE
R²
maximum absolute error
P95 absolute error
P99 absolute error
highest-risk body-part accuracy
highest-risk level accuracy
```

Also report metrics by:

```text
Head / Shoulders / Hips / Heels
CENTER / LEFT / RIGHT
duration band
subject
sensor mat
mattress
risk level
```

Recommended duration bands:

```text
0–1 min
1–5 min
5–15 min
15–30 min
30–60 min
60–120 min
120+ min
```

Also report the **worst-performing subject/subgroup**, not only the population average.

---

# 17. Model Purpose: Student of an Engineering Teacher

The current neural network is primarily learning to approximate a deterministic engineering teacher that itself depends on pressure and duration.

Conceptually:

```text
ADC
  ↓
normalized load
  ↓
pressure + duration
  ↓
engineering teacher
  ↓
target risk score
  ↓
small MLP student model
```

This is valid for:

- embedded prototype integration
- replacing a more complex computation with a compact model
- validating the deployment toolchain
- preparing for later population-trained models

It does **not** independently establish clinical predictive validity.

For the present synthetic stage, benchmark both:

```text
A. direct teacher-function implementation
B. MLP approximation
```

on the target MCU for:

- flash
- RAM
- latency
- power
- numerical error
- implementation complexity

The MLP becomes more valuable as the model evolves beyond a fixed teacher equation and learns from diverse real-subject data.

---

# 18. PyTorch → ONNX

Example export:

```python
import torch

model = PressureRiskMLP()
model.load_state_dict(
    torch.load(
        "pressure_risk_mlp.pt",
        map_location="cpu"
    )
)

model.eval()

dummy = torch.randn(1, 12)

torch.onnx.export(
    model,
    dummy,
    "pressure_risk_mlp.onnx",
    input_names=["input"],
    output_names=["output"],
    dynamic_axes={
        "input": {0: "batch"},
        "output": {0: "batch"}
    },
    opset_version=13
)
```

After export, run representative test vectors through both PyTorch and ONNX Runtime and compare outputs.

---

# 19. ONNX → TFLite for Silicon Labs

Do **not** use `tf2onnx` for ONNX → TFLite conversion.

`tf2onnx` is a TensorFlow/TFLite → ONNX converter and is the wrong conversion direction for this deployment path.

For current Silicon Labs tooling, use **Simplicity Machine Learning**.

Check version:

```bash
sml --version
```

The converter is available in Simplicity Machine Learning CLI versions that provide:

```bash
sml convert
```

Convert the ONNX model:

```bash
sml convert \
    pressure_risk_mlp.onnx \
    --output pressure_risk_mlp.tflite \
    --save-manifest \
    --log-level info
```

For help:

```bash
sml convert --help
```

## Current converter behavior

The Silicon Labs converter currently produces a **float32 TFLite model**.

Do not assume that conversion applies:

- INT8 quantization
- FP16 quantization

unless a later verified toolchain explicitly does so.

Always validate the generated `.tflite` model against the ONNX/PyTorch model using representative inputs.

---

# 20. Simplicity Machine Learning Setup

On Windows, use WSL2/Linux for the Silicon Labs ML tooling when required.

Start WSL:

```bash
wsl
```

Check whether `sml` is installed:

```bash
which sml
sml --version
sml --help
```

If Silicon Labs Toolchain (`slt`) is installed:

```bash
which slt
slt --version
```

Install / update Simplicity Machine Learning through SLT as appropriate for the installed Silicon Labs environment.

Example discovery:

```bash
slt where sml
```

or inspect installed tools:

```bash
find "$HOME/.silabs/slt/installs" \
    -type f \
    -name "sml" \
    -perm -111 \
    2>/dev/null
```

If a manually installed binary directory must be added to PATH:

```bash
export PATH="/path/to/sml-directory:$PATH"
```

To persist it:

```bash
echo 'export PATH="/path/to/sml-directory:$PATH"' >> ~/.bashrc
source ~/.bashrc
```

---

# 21. Current Windows / WSL Project Path Example

Example Windows folder:

```text
C:\Users\KIIT0001\Downloads\VitalS model
```

Equivalent WSL path:

```text
/mnt/c/Users/KIIT0001/Downloads/VitalS model
```

Use:

```bash
cd "/mnt/c/Users/KIIT0001/Downloads/VitalS model"
pwd
ls -lah
```

---

# 22. TFLite Parity Verification

A format conversion is not considered complete until outputs are compared.

Required parity chain:

```text
PyTorch
   ↕
ONNX
   ↕
TFLite
```

Use the same representative inputs for all three runtimes.

Store results in version-controlled regression artifacts such as:

```text
onnx_test_report.json
onnx_test_predictions.csv
tflite_test_report.json
tflite_test_predictions.csv
```

Recommended checks:

```text
maximum absolute difference
mean absolute difference
relative error
per-output difference
worst test vector
```

---

# 23. Golden Preprocessing / Firmware Test Vectors

Model parity alone is insufficient.

The embedded firmware also performs preprocessing:

```text
position
duration_sec
ADC values
   ↓
one-hot posture
log-duration
ADC → load
exposure features
   ↓
12-element model tensor
```

Create a regression file such as:

```text
firmware_golden_vectors.csv
```

Recommended columns:

```text
position
duration_sec

head_adc
shoulders_adc
hips_adc
heels_adc

position_CENTER
position_LEFT
position_RIGHT

log_duration_normalized

head_load
shoulders_load
hips_load
heels_load

head_exposure_scaled
shoulders_exposure_scaled
hips_exposure_scaled
heels_exposure_scaled

expected_head_risk
expected_shoulders_risk
expected_hips_risk
expected_heels_risk
```

Run the same vectors through:

```text
Python preprocessing
EFR32 preprocessing
PyTorch
ONNX Runtime
TFLite host runtime
EFR32 device inference
```

Acceptance requires preprocessing and inference outputs to match within documented tolerances.

---

# 24. Silicon Labs AI/ML SDK 3.x Integration

For current AI/ML SDK 3.x projects, use the **ML Model (`ml_model`) component** and `.mlconf` workflow.

General workflow:

```text
pressure_risk_mlp.tflite
        ↓
ML Model component
        ↓
config/tflite/<instance>.mlconf
        ↓
MVP Compiler / project generation
        ↓
generated model files
        ↓
sl_ml_model_* runtime APIs
```

## Add the model

1. Open the Simplicity Studio project `.slcp`.
2. Enable the Silicon Labs AI/ML SDK extension.
3. Add an instance of the **ML Model (`ml_model`)** component.
4. Configure the generated `.mlconf` file.
5. Set the model path to `pressure_risk_mlp.tflite`.
6. Regenerate the project.
7. Confirm generated model artifacts are present.

Generated filenames depend on the model/component instance.

Typical generated artifacts include model headers and generated C++ model data.

## Runtime API

AI/ML SDK 3.x uses the unified model runtime API family:

```c
sl_ml_model_init(...)
sl_ml_model_run(...)
sl_ml_model_deinit(...)
```

Use the model handle generated for the configured ML Model instance.

If this project was originally built with AI/ML SDK 2.x, treat the migration to 3.x as a deliberate code change because the model-component and runtime APIs changed.

---

# 25. VitalSense C/C++ Wrapper

Keep the application-specific VitalSense wrapper separate from the Silicon Labs generated model layer.

Recommended architecture:

```text
Application
    ↓
pressure_risk_ml_predict(...)
    ↓
VitalSense preprocessing
    ↓
12 float model features
    ↓
Silicon Labs sl_ml_model_* API
    ↓
TFLite model
    ↓
4 normalized engineering risk scores
```

The wrapper should contain or call the frozen production implementations for:

- posture encoding
- duration normalization
- ADC-to-load mapping
- exposure feature calculation
- input tensor population
- inference
- output scaling
- LOW/MEDIUM/HIGH classification
- highest-risk body-part selection

---

# 26. Highest-Risk Body Part

The highest-risk region should be derived from:

```python
regional_scores = {
    "head": head_risk_score,
    "shoulders": shoulders_risk_score,
    "hips": hips_risk_score,
    "heels": heels_risk_score,
}

highest_risk_body_part = max(
    regional_scores,
    key=regional_scores.get
)
```

For testing, explicitly handle exact or near ties.

A change in highest-risk body part is less significant when the two leading regional scores are nearly equal.

Store or calculate:

```python
highest_score
second_highest_score
risk_margin = highest_score - second_highest_score
```

---

# 27. Model Release Acceptance

Before a model is released to firmware, verify all of the following.

## Data

```text
[ ] Dataset version recorded
[ ] Subject split recorded
[ ] No subject leakage
[ ] Calibration fitted from TRAIN only
[ ] Validation population used for tuning
[ ] Final TEST population remained untouched
```

## Teacher / targets

```text
[ ] Teacher version recorded
[ ] Output clipping behavior verified
[ ] Risk thresholds versioned
[ ] Synthetic vs real labels clearly distinguished
```

## Features

```text
[ ] 12-feature order frozen
[ ] Exact exposure formula documented
[ ] Duration behavior documented
[ ] ADC calibration constants versioned
[ ] Python and firmware preprocessing parity tested
```

## Model

```text
[ ] PyTorch metrics accepted
[ ] ONNX parity passed
[ ] TFLite parity passed
[ ] Worst-case error reviewed
[ ] Per-region performance reviewed
[ ] Per-posture performance reviewed
[ ] Highest-risk margin analysis reviewed
```

## Device

```text
[ ] Model compiles for EFR32xG26
[ ] Golden vectors pass on device
[ ] Flash usage measured
[ ] RAM usage measured
[ ] Inference latency measured
[ ] Device output matches reference within tolerance
```

---

# 28. Recommended Version Metadata

Every model release should record:

```text
model_version
dataset_version
training_script_commit
preprocessing_version
teacher_model_version
risk_threshold_version

q05/q95 calibration version

PyTorch version
ONNX version
ONNX Runtime version
Simplicity Machine Learning version

Simplicity Studio version
Simplicity SDK version
Silicon Labs AI/ML SDK version

EFR32 part number
board revision
firmware version
compiler version
```

---

# 29. Future Real-Subject Generalization

The current subject-wise synthetic test demonstrates performance on **unseen synthetic subjects produced by the same synthetic generation pipeline**.

It does not by itself prove generalization to unseen humans.

Future validation should include independent real subjects across:

- different weights
- different heights
- different body shapes
- different days/sessions
- CENTER / LEFT / RIGHT positions
- different sensor mats
- different mattress conditions
- realistic sensor-placement variation

For stronger deployment validation, reserve:

```text
new subject
+
new physical sensor mat
```

for a hardware holdout test.

---

# 30. Current Model Limitations

The current model should be understood with the following limitations:

1. Targets are generated from a synthetic engineering teacher.
2. Current calibration constants may reflect limited real-subject/hardware variation.
3. Existing reported metrics use a train/test split without a separately documented validation set.
4. The exact exposure-feature formula must be recovered from and documented from the training source code.
5. The previous documentation did not state whether teacher targets were clipped to `[0,1]`.
6. Current test performance demonstrates synthetic-pipeline generalization, not clinical validation.
7. The 1,735 real/stable rows require clearer provenance documentation relative to the 60,000 synthetic rows.

These are documentation and validation issues to resolve before the next frozen model release.

---

# 31. Recommended Next Training Pipeline

```text
REAL SENSOR RECORDINGS
        │
        ├── ADC distributions
        ├── posture distributions
        ├── no-load baseline
        └── hardware variation
        │
        ▼
SUBJECT-WISE SPLIT
 TRAIN / VALIDATION / TEST
        │
        ▼
TRAIN-ONLY CALIBRATION
        │
        ├── ADC → load
        └── normalization
        │
        ▼
SYNTHETIC / ENGINEERING TARGET GENERATION
        │
        ├── versioned teacher
        └── explicit [0,1] target behavior
        │
        ▼
12-FEATURE PREPROCESSING
        │
        ▼
MLP
12 → 16 → 8 → 4
        │
        ▼
VALIDATION
        │
        ├── architecture
        ├── features
        ├── thresholds
        └── hyperparameters
        │
        ▼
FROZEN TEST
        │
        ├── overall metrics
        ├── per-region
        ├── per-posture
        ├── duration bands
        ├── worst-subgroup
        └── risk-margin analysis
        │
        ▼
PyTorch
        │
        ▼
ONNX
        │
        ├── parity
        ▼
TFLite
        │
        ├── parity
        ▼
EFR32xG26
        │
        ├── golden vectors
        ├── latency
        ├── RAM
        └── flash
```

---

# 32. Disclaimer

> **Synthetic engineering risk index only.**
>
> This model is intended for prototype system integration, embedded algorithm development, pressure-distribution research, and engineering evaluation.
>
> It is **not a clinically validated pressure-ulcer probability model, medical diagnosis system, or substitute for clinical judgment**.

---

# 33. License

This project is licensed under the [Apache License 2.0](../../../LICENSE.md).

SPDX-License-Identifier: Apache-2.0

Copyright 2025 VitalSense Project Contributors

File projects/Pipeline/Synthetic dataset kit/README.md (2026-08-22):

# VitalSense Synthetic Dataset Kit

This folder contains the **end-to-end pipeline** for generating synthetic pressure-risk datasets, training the prototype MLP, and running inference. It transforms paired Smart Belt (IMU) + Smart Bedsheet (FSR) recordings into a supervised learning problem for on-device edge AI.

---

## Pipeline Overview

```
┌─────────────────────┐     ┌─────────────────────┐     ┌─────────────────────┐
│  Source Recordings  │     │  Synthetic Dataset  │     │  Trained Model      │
│                     │     │                     │     │                     │
│  vitalsense_data_   │────►│  build_pressure_    │────►│  pressure_risk_     │
│  20260807_020412.csv│     │  risk_dataset.py    │     │  mlp.pt             │
│  xg26_position_     │     │                     │     │  pressure_risk_     │
│  dataset3.csv       │     │  • Align 1 Hz       │     │  model_metadata.json│
│                     │     │  • Stable segments  │     │                     │
│  (60 Hz belt +     │     │  • Calibrate ADC    │     │  ONNX / TFLite      │
│   FSR bedsheet)    │     │  • Teacher risk fn  │     │  (see /model)       │
└─────────────────────┘     └─────────────────────┘     └─────────────────────┘
                                    │
                                    ▼
                         ┌─────────────────────┐
                         │  Inference Helper   │
                         │  pressure_risk_     │
                         │  inference.py       │
                         └─────────────────────┘
```

---

## Files

| File | Purpose |
|---|---|
| `build_pressure_risk_dataset.py` | **Main pipeline**: aligns sources → extracts stable segments → calibrates ADC → generates synthetic subjects → trains MLP → exports model + metadata |
| `pressure_risk_inference.py` | Standalone inference helper (CLI + Python API) using trained model + metadata |
| `pressure_risk_model_metadata.json` | Full provenance: calibration, teacher config, posture stats, model architecture, metrics |
| `Pressure_Ulcer_Prevention_System_Project.md` | System-level documentation (architecture, users, communication flow) |

---

## Source Data Requirements

The pipeline expects two CSV files (paths hardcoded at top of `build_pressure_risk_dataset.py`):

| File | Source | Key Columns |
|---|---|---|
| `vitalsense_data_20260807_020412.csv` | Smart Bedsheet (FSR) | `computer_timestamp`, `head_average`, `shoulders_average`, `hips_average`, `heels_average` |
| `xg26_position_dataset3.csv` | Smart Belt (IMU) | `time_sec`, `position` (CENTER/LEFT/RIGHT) |

> **Note:** Update `BED_CSV` and `BELT_CSV` constants in the script for your local paths.

---

## Teacher Risk Function (Synthetic Labels)

Labels are generated by a **physics-inspired risk function**, not clinical ground truth:

```python
# Effective load above relief floor
effective = clip((load - relief_floor) / (1.0 - relief_floor), 0, 1)

# Pressure-time dose
dose = effective^pressure_exponent * duration_sec / reference_duration_seconds

# Risk index 0–100
risk = 100 * (1 - exp(-risk_gain * dose))
```

| Parameter | Value | Meaning |
|---|---|---|
| `reference_duration_seconds` | 7200 (2 hrs) | Time constant for dose accumulation |
| `relief_floor` | 0.10 | Load below this contributes no risk |
| `pressure_exponent` | 1.50 | Nonlinear pressure weighting |
| `risk_gain` | 1.50 | Global scaling |
| `low_medium_threshold` | 35.0 | Risk level boundary |
| `medium_high_threshold` | 70.0 | Risk level boundary |

---

## Synthetic Subject Generation

| Setting | Value |
|---|---|
| `N_SYNTHETIC_SUBJECTS` | 120 |
| `ROWS_PER_SUBJECT` | 500 |
| **Total rows** | 60,000 |
| **Split** | 80/20 subject-wise (96/24 subjects) |

Each synthetic row:
1. Samples a **source stable row** matching the target posture
2. Applies **subject/global/mattress variation** (log-normal factors)
3. Adds **slow drift + measurement noise**
4. Converts load → ADC using calibrated q05/q95
5. Computes **teacher risk** for the sampled duration

---

## ADC Calibration

Uses **5th / 95th percentiles** from the full bedsheet recording per zone:

| Zone | q05 (low load) | q95 (high load) |
|---|---|---|
| Head | 3119 | 3932 |
| Shoulders | 3537 | 3994 |
| Hips | 3007 | 3909 |
| Heels | 3222 | 4021 |

```
load = clip((adc - q05) / (q95 - q05), 0, 1)
```

---

## Model Architecture

```
Input (12) → Linear(16) → ReLU → Linear(8) → ReLU → Linear(4) → Sigmoid
```

| Layer | Size |
|---|---|
| Input | 12 |
| Hidden 1 | 16 |
| Hidden 2 | 8 |
| Output | 4 (head, shoulders, hips, heels risk 0–1) |

**Parameters:** 380

### Input Features (fixed order)

| Index | Feature | Derivation |
|---|---|---|
| 0–2 | `position_CENTER/LEFT/RIGHT` | One-hot |
| 3 | `log_duration_normalized` | `log1p(duration) / log1p(7200)` |
| 4–7 | `head/shoulders/hips/heels_load` | ADC → load via q05/q95 |
| 8–11 | `*_exposure_scaled` | `clip(effective^1.5 * duration / 7200, 0, 3) / 3` |

### Output

| Index | Zone | Range |
|---|---|---|
| 0 | Head | [0, 1] |
| 1 | Shoulders | [0, 1] |
| 2 | Hips | [0, 1] |
| 3 | Heels | [0, 1] |

---

## Running the Pipeline

### Prerequisites

```bash
pip install numpy pandas torch scikit-learn
```

### Generate Dataset + Train Model

```bash
cd "Synthetic dataset kit"
python build_pressure_risk_dataset.py
```

**Outputs:**
- `/mnt/data/synthetic_pressure_ulcer_risk_dataset.csv` (60k rows)
- `/mnt/data/pressure_risk_mlp_v2.pt` (PyTorch state dict)
- `/mnt/data/pressure_risk_model_metadata_v2.json` (full provenance)

> The script also prints the metadata JSON to stdout.

---

## Inference (Python API)

```python
from pressure_risk_inference import PressureRiskPredictor

predictor = PressureRiskPredictor(
    model_path=Path("pressure_risk_mlp_v2.pt"),
    metadata_path=Path("pressure_risk_model_metadata_v2.json")
)

result = predictor.predict(
    position="LEFT",
    duration_sec=3600,      # 1 hour
    adc_values=[3500, 3800, 3200, 3600]  # head, shoulders, hips, heels
)

print(result["highest_risk_body_part"])  # "HIPS"
print(result["zones"]["hips"]["risk_score"])  # 42.3
print(result["zones"]["hips"]["risk_level"])  # "MEDIUM"
```

### Inference (CLI)

```bash
python pressure_risk_inference.py \
    --position LEFT \
    --duration-sec 3600 \
    --head 3500 \
    --shoulders 3800 \
    --hips 3200 \
    --heels 3600
```

---

## Output Schema (Inference)

```json
{
  "position": "LEFT",
  "same_position_duration_sec": 3600.0,
  "zones": {
    "head": {
      "adc": 3500.0,
      "normalized_load": 0.47,
      "risk_score": 18.2,
      "risk_level": "LOW"
    },
    "shoulders": { ... },
    "hips": { ... },
    "heels": { ... }
  },
  "highest_risk_body_part": "HIPS",
  "highest_risk_score": 42.3,
  "highest_risk_level": "MEDIUM",
  "warning": "Synthetic engineering risk index only; not a clinically validated..."
}
```

---

## Key Configuration Constants

| Constant | Default | Location |
|---|---|---|
| `ADC_DECREASES_WITH_LOAD` | `False` | Top of build script |
| `STABLE_SEGMENT_MIN_SECONDS` | 300 | Top of build script |
| `STABLE_MARGIN_SECONDS` | 20 | Top of build script |
| `SEED` | 42 | Top of build script |

---

## Disclaimer

> **Synthetic engineering risk index only.** Not a clinically validated pressure-ulcer probability or diagnostic model. Intended for prototype system integration and algorithm development.

---

## Related

- **Model deployment:** `/model/README.md` (ONNX/TFLite conversion, EFR32 integration)
- **EFR32 firmware:** `/EFR xG26 firmware/bt_imu_mode/README.md`
- **ESP32 firmware:** `/ESP32 firmware/README.md`
- **System architecture:** `Pressure_Ulcer_Prevention_System_Project.md`

---

## License

This project is licensed under the [Apache License 2.0](../../../LICENSE.md).

SPDX-License-Identifier: Apache-2.0  
Copyright 2025 VitalSense Project Contributors

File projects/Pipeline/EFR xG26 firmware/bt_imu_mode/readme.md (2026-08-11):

# VitalSense EFR32xG26 Firmware

**Firmware Version:** `VITALSENSE_XG26_IMU_BLE_ML_V1`

This firmware runs on the **Silicon Labs EFR32xG26 (BRD2608A)** and serves as the IMU + BLE central + ML inference node in the VitalSense pressure ulcer prevention system.

---

## System Overview

```
┌─────────────────────────────────────────────────────────────────┐
│                     VITALSENSE SYSTEM                           │
├─────────────────────────────────────────────────────────────────┤
│                                                                 │
│  ┌──────────────┐      BLE (Central)      ┌────────────────┐  │
│  │  EFR32xG26   │ ◄─────────────────────► │   ESP32-C3     │  │
│  │  (This FW)   │      GATT Client        │  (Peripheral)  │  │
│  └──────┬───────┘                         └───────┬────────┘  │
│         │                                         │            │
│         │ IMU (ICM-40627)                         │ 8× FSR     │
│         │ ~60 Hz sampling                         │ sensors    │
│         ▼                                         ▼            │
│  ┌─────────────────────────────────────────────────────────┐  │
│  │              pressure_risk_mlp (TFLite Micro)            │  │
│  │  Inputs: posture + duration + 4 plate ADC averages       │  │
│  │  Output: 4 risk scores (0-100) for Head/Shoulders/Hips/Heels│
│  └─────────────────────────────────────────────────────────┘  │
│                                                                 │
└─────────────────────────────────────────────────────────────────┘
```

---

## EFR32xG26 Responsibilities

| # | Responsibility | Details |
|---|---|---|
| 1 | **IMU Calibration** | Calibrate CENTER / LEFT / RIGHT postures using ICM-40627 accelerometer |
| 2 | **Posture Tracking** | Classify posture at ~60 Hz, track uninterrupted duration |
| 3 | **BLE Central** | Scan for `VitalSense-ESP32C3`, connect, discover GATT |
| 4 | **FSR Request** | After posture threshold (default 60s), request 8-FSR array once/sec |
| 5 | **FSR Decode** | Parse `[0x81, 0x08, FSR0_L, FSR0_H, ... FSR7_L, FSR7_H]` |
| 6 | **Plate Averaging** | Average 8 FSRs into 4 plates: Head, Shoulders, Hips, Heels |
| 7 | **ML Inference** | Run `pressure_risk_mlp` with posture + duration + 4 plate ADCs |
| 8 | **Risk TX** | Send 4 risk packets `[0x02, bodyId, risk0-100, avoidFlag]` to ESP32 |
| 9 | **State TX** | Send periodic posture+duration summary `[0x03, pos, dur, risk...]` |

---

## Hardware

| Component | Part | Connection |
|---|---|---|
| MCU | EFR32MG26B510F3200IM68 | BRD2608A (xG26 Dev Kit) |
| IMU | ICM-40627 | I²C (enabled via PA10) |
| Buttons | BTN0, BTN1 | On-board |
| RGB LED | status_rgb | PWM (RED/GREEN/BLUE) |
| Debug | VCOM | USART0 (115200 baud) |

---

## Button Mapping

| Button | Action |
|---|---|
| **BTN0** | During calibration: CENTER → LEFT → RIGHT<br>After calibration: Restart calibration |
| **BTN1** | Toggle Awake ↔ Standby |

---

## RGB LED Status Codes

| Color | State |
|---|---|
| **OFF** | Standby (BTN1 to wake) |
| **YELLOW** | Calibration required (press BTN0) |
| **RED** | IMU / ML / BLE error |
| **BLUE** | Scanning for ESP32 |
| **PURPLE** | Connecting / Discovering GATT |
| **CYAN** | ESP32 link ready |
| **GREEN** | Waiting for FSR response |

---

## BLE Protocol (EFR32 → ESP32)

**Target Device:** `VitalSense-ESP32C3`  
**Service UUID:** `7a0a0001-5b8a-4f4c-9d1d-8b4e3d7a1000`  
**RX Char (EFR→ESP):** `7a0a0002-5b8a-4f4c-9d1d-8b4e3d7a1000` (Write w/ Response)  
**TX Char (ESP→EFR):** `7a0a0003-5b8a-4f4c-9d1d-8b4e3d7a1000` (Notify)

### Commands (EFR32 → ESP32)

| CMD | Payload | Description |
|-----|---|---|
| `0x01` | — | Request fresh 8-FSR array |
| `0x02` | `bodyId, risk(0-100), avoidFlag` | ML risk update (×4 bodies) |
| `0x03` | `pos, durationSec, riskValid, zoneId, score, level` | Posture + summary state |

### Response (ESP32 → EFR32)

| Byte | Value |
|---|---|
| `[0]` | `0x81` |
| `[1]` | `0x08` (sensor count) |
| `[2..17]` | 8 × `uint16_t` little-endian FSR values |

### Body IDs

| ID | Body Part |
|----|---|
| 1 | Head |
| 2 | Shoulders |
| 3 | Hips |
| 4 | Heels |

### Risk Levels

| Level | Value |
|---|---|
| LOW | 0 |
| MEDIUM | 1 |
| HIGH | 2 |

> **Note on `avoidReturnFlag`**: Currently always `0`. Reserved for future forbidden-posture logic.

---

## ML Model: `pressure_risk_mlp`

- **Framework:** TensorFlow Lite Micro (via Silicon Labs AI/ML SDK)
- **Inputs (5):** `posture (0/1/2)`, `duration_sec`, `head_adc`, `shoulders_adc`, `hips_adc`, `heels_adc`
- **Outputs (4):** Risk scores 0–100 for Head, Shoulders, Hips, Heels
- **Model File:** `config/tflite/pressure_risk_mlp.tflite`

---

## Key Timing Constants

| Constant | Value | Description |
|---|---|---|
| `POSITION_SAMPLE_RATE_HZ` | 60 | IMU sampling / posture classification rate |
| `RISK_PREDICTION_THRESHOLD_SECONDS` | 60 | Uninterrupted posture before ML starts |
| `RISK_PREDICTION_INTERVAL_SECONDS` | 1 | ML inference interval after threshold |
| `FSR_RESPONSE_TIMEOUT_SECONDS` | 3 | Max wait for ESP32 FSR response |
| `BLE_SCAN_INTERVAL_UNITS` | 80 | 50 ms scan interval |
| `BLE_CONNECTION_INTERVAL_UNITS` | 24 | 30 ms connection interval |

---

## Building & Flashing

### Prerequisites

- **Simplicity Studio 5** (v5.2+)
- **Silicon Labs Gecko SDK** 2026.6.0
- **EFR32xG26 BRD2608A** dev kit

### Steps

1. Open Simplicity Studio
2. `File → Import → Silicon Labs → Project from SLCP`
3. Select `bt_imu_mode.slcp`
4. Connect BRD2608A (power switch → **AEM** position)
5. Build project (hammer icon)
6. Flash (debug icon)

### Post-Build (for OTA DFU)

Add a post-build step to generate `.gbl`:
```bash
commander gbl create output.gbl --app output.s37
```

---

## Debug Output (VCOM @ 115200)

```
[IMU] Ready. ID=0x47 actual_rate=100 Hz
[ML] Model ready
[ML] Prediction gate = 60 s uninterrupted posture
[CAL] Press BTN0 to capture the requested posture
[CAL] Capturing CENTER. Keep still.
[CAL] CENTER reference mg: X=12 Y=-4 Z=1012
[CAL] CENTER saved. Hold LEFT and press BTN0
...
[CAL] COMPLETE
[BLE] Starting scan for VitalSense-ESP32C3
[BLE] Scanning for VitalSense-ESP32C3
[BLE] Found VitalSense-ESP32C3, connecting...
[BLE] Connected, discovering services...
[BLE] GATT discovery complete, enabling TX notifications
[BLE] Link ready
RISK_WAIT,CENTER,10,60
RISK_WAIT,CENTER,20,60
...
[FSR] Request sent | position=CENTER duration=60 s
[FSR] Response received: 1234 2345 3456 4567 5678 6789 7890 8901
[ML] pred: head=12.3 should=8.7 hips=45.2 heels=3.1 max=HIPS(45.2) lvl=MEDIUM
[BLE] Risk write started body=1
[BLE] Risk write started body=2
[BLE] Risk write started body=3
[BLE] Risk write started body=4
```

---

## Project Structure

```
bt_imu_mode/
├── app.c / app.h              # Main application logic
├── main.c                     # Silicon Labs main() entry
├── pressure_risk_ml_xg26.h/.cpp  # ML model C API wrapper
├── bt_imu_mode.slcp           # Project configuration
├── config/
│   ├── tflite/pressure_risk_mlp.tflite   # TFLite model
│   └── *.h                       # Component configs
├── autogen/                    # Auto-generated SDK code
├── cmake_gcc/                  # GCC/CMake build
├── image/                      # README images
└── firmware file/
    └── bt_imu_mode.s37         # Pre-built firmware
```

---

## References

- [UG103.14: Bluetooth LE Fundamentals](https://www.silabs.com/documents/public/user-guides/ug103-14-fundamentals-ble.pdf)
- [QSG169: Bluetooth SDK v3.x Quick Start](https://www.silabs.com/documents/public/quick-start-guides/qsg169-bluetooth-sdk-v3x-quick-start-guide.pdf)
- [UG434: Bluetooth C SoC Developer's Guide](https://www.silabs.com/documents/public/user-guides/ug434-bluetooth-c-soc-dev-guide-sdk-v3x.pdf)
- [ICM-40627 Datasheet](https://invensense.tdk.com/products/motion-tracking/6-axis/icm-40627/)

---

## License

SPDX-License-Identifier: Zlib  
Copyright 2025 Silicon Laboratories Inc. / VitalSense Project Contributors

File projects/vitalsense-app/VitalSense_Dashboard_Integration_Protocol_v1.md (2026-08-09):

# VitalSense Dashboard Integration Specification

**Protocol:** VitalSense Protocol v1  
**Transport:** UDP broadcast over IPv4  
**UDP Port:** `5005`  
**Payload Format:** UTF-8 JSON  
**Typical Update Rate:** approximately 1 packet per second  
**Network Requirement:** Dashboard receiver and ESP32-C3 must be on the same Wi-Fi/LAN subnet.

---

# 1. Purpose

This document defines how a VitalSense dashboard should receive, interpret, validate, and display data broadcast by the ESP32-C3.

The overall system is:

```text
FSR Sensors
    |
    v
ESP32-C3  <------ BLE ------>  EFR32xG26
                                   |
                                   +-- IMU posture detection
                                   +-- posture duration
                                   +-- ML pressure-risk inference
    |
    | Wi-Fi / UDP broadcast
    v
UDP port 5005
    |
    +----------------------+
    |                      |
    v                      v
Dashboard               Mobile App
```

The ESP32-C3 is the Wi-Fi gateway.

The dashboard does **not** need to connect to the EFR32xG26.

The dashboard does **not** need BLE.

The dashboard only consumes the UDP JSON broadcast generated by the ESP32-C3.

---

# 2. Network Behaviour

The ESP32 does not send data to one hard-coded Raspberry Pi or PC.

It calculates the broadcast address of the Wi-Fi subnet and sends the JSON packet to:

```text
<subnet broadcast address>:5005
```

Example:

```text
ESP32 IP       : 192.168.137.25
Subnet Mask    : 255.255.255.0
Broadcast IP   : 192.168.137.255
UDP Port       : 5005
```

The ESP32 sends to:

```text
192.168.137.255:5005
```

Any device on that subnet listening on UDP port `5005` can receive the packet.

The receiver should therefore **not require the ESP32 IP address to be configured manually**.

---

# 3. Important Dashboard Architecture

## 3.1 Native/Desktop Dashboard

A native desktop program can listen directly on:

```text
0.0.0.0:5005
```

Examples:

- Python application
- C#/.NET application
- Java application
- Electron application using a Node.js backend process
- Raspberry Pi application
- Native Linux/Windows service

---

## 3.2 Browser-Based Web Dashboard

A normal web browser cannot directly open a raw UDP listening socket.

Therefore a browser dashboard should use this architecture:

```text
ESP32
  |
  | UDP broadcast :5005
  v
Dashboard Backend / Gateway
  |
  | WebSocket / HTTP / SSE
  v
Web Browser Dashboard
```

Recommended:

```text
ESP32
  |
  v
Python / Node.js / .NET UDP Listener
  |
  v
WebSocket
  |
  v
React / Vue / Angular / HTML Dashboard
```

The backend listener receives the UDP packet and forwards the parsed JSON to the browser.

---

# 4. UDP Receiver Configuration

The receiver should bind to:

```text
IP Address : 0.0.0.0
Port       : 5005
Protocol   : UDP IPv4
Encoding   : UTF-8
```

Example concept:

```text
socket(AF_INET, SOCK_DGRAM)
bind("0.0.0.0", 5005)
receive()
decode UTF-8
parse JSON
```

Do not bind only to one specific ESP32 IP.

---

# 5. VitalSense Protocol v1 JSON

The ESP32 broadcasts a JSON object similar to:

```json
{
  "protocol": 1,
  "deviceId": "VS-BED-001",
  "bed": 1,

  "position": "LEFT",
  "positionDuration": 102,

  "plates": {
    "head": 484,
    "shoulders": 586,
    "hips": 337,
    "heels": 668
  },

  "fsr": [
    4,
    964,
    46,
    1127,
    4,
    670,
    280,
    1056
  ],

  "riskValid": true,

  "risk": {
    "head": 12,
    "shoulders": 18,
    "hips": 42,
    "heels": 16
  },

  "highestRisk": {
    "zone": "HIPS",
    "score": 42,
    "level": "MEDIUM"
  },

  "avoidReturn": {
    "head": 0,
    "shoulders": 0,
    "hips": 0,
    "heels": 0
  },

  "uptime": 1217
}
```

---

# 6. Field Definitions

## `protocol`

```json
"protocol": 1
```

Type:

```text
integer
```

Meaning:

VitalSense communication protocol version.

Dashboard requirement:

```text
Accept protocol = 1
```

If a future packet contains a different protocol version, the software should log it and avoid assuming that every field has the same meaning.

---

## `deviceId`

```json
"deviceId": "VS-BED-001"
```

Type:

```text
string
```

Meaning:

Unique logical identifier for the VitalSense bed/device.

Use this as the primary device identifier in the dashboard.

Recommended UI:

```text
Device: VS-BED-001
```

Do not use IP address as the permanent identity of the device because DHCP may change the ESP32 IP.

---

## `bed`

```json
"bed": 1
```

Type:

```text
integer
```

Meaning:

Bed number assigned to this VitalSense unit.

Recommended UI:

```text
Bed 01
```

---

# 7. Patient Position

## `position`

Possible current values:

```text
CENTER
LEFT
RIGHT
```

Example:

```json
"position": "LEFT"
```

Meaning:

Current body orientation detected by the EFR32xG26 IMU.

Dashboard display:

```text
Current Position
LEFT
```

Suggested human-readable labels:

```text
CENTER -> Center / Supine
LEFT   -> Left Side
RIGHT  -> Right Side
```

The UI may use more descriptive wording, but the raw protocol values should remain unchanged internally.

---

# 8. Position Duration

## `positionDuration`

Example:

```json
"positionDuration": 102
```

Type:

```text
integer
```

Unit:

```text
seconds
```

Meaning:

Continuous uninterrupted time that the patient has remained in the current detected position.

If the patient changes position, this value resets.

Example:

```text
position         = LEFT
positionDuration = 102
```

Means:

```text
Patient has remained LEFT for approximately 102 seconds.
```

Recommended dashboard formatting:

```text
102 seconds -> 01:42
3661 seconds -> 01:01:01
```

Recommended display:

```text
Current Position Duration
01:42
```

---

# 9. FSR Mapping

There are 8 physical FSR sensors.

The array:

```json
"fsr": [fsr0, fsr1, fsr2, fsr3, fsr4, fsr5, fsr6, fsr7]
```

maps as follows:

| FSR | Body Region |
|---|---|
| FSR0 | Head sensor A |
| FSR1 | Head sensor B |
| FSR2 | Shoulders sensor A |
| FSR3 | Shoulders sensor B |
| FSR4 | Hips sensor A |
| FSR5 | Hips sensor B |
| FSR6 | Heels sensor A |
| FSR7 | Heels sensor B |

The values are raw ESP32 ADC readings.

Current ADC range is nominally:

```text
0 ... 4095
```

Example:

```json
"fsr": [4, 964, 46, 1127, 4, 670, 280, 1056]
```

For most end-user dashboards, individual FSR values should be placed on a diagnostics/service screen rather than the primary nurse/operator screen.

---

# 10. Plate Values

The ESP32 averages each pair of FSRs.

```json
"plates": {
  "head": 484,
  "shoulders": 586,
  "hips": 337,
  "heels": 668
}
```

Calculation:

```text
Head      = (FSR0 + FSR1) / 2
Shoulders = (FSR2 + FSR3) / 2
Hips      = (FSR4 + FSR5) / 2
Heels     = (FSR6 + FSR7) / 2
```

These are raw pressure-related ADC values.

Important:

Do not interpret the raw ADC number directly as kilograms, Newtons, mmHg, or another physical pressure unit unless a separate physical calibration is completed.

Recommended UI wording:

```text
Head Load      484
Shoulders Load 586
Hips Load      337
Heels Load     668
```

or show these values only on a diagnostic screen.

---

# 11. Risk Availability

## `riskValid`

Example before ML assessment:

```json
"riskValid": false
```

Example after ML assessment:

```json
"riskValid": true
```

This is one of the most important fields for dashboard logic.

The current firmware does not run ML inference until the uninterrupted posture duration reaches the configured threshold.

Current development threshold:

```text
60 seconds
```

Therefore before the threshold:

```text
riskValid = false
```

The dashboard should display:

```text
Waiting for assessment
```

Do **not** display the risk fields as real risk percentages when `riskValid` is `false`.

---

# 12. Risk Values

After a valid ML prediction:

```json
"risk": {
  "head": 12,
  "shoulders": 18,
  "hips": 42,
  "heels": 16
}
```

Type:

```text
integer
```

Nominal range:

```text
0 ... 100
```

Meaning:

ML-derived risk index for each body region.

Display:

```text
Head       12%
Shoulders  18%
Hips       42%
Heels      16%
```

Important:

These values are an engineering/model risk index. The dashboard should not present them as a clinically validated probability unless clinical validation is separately completed.

---

# 13. Risk Before Assessment

Before the first valid ML inference, the ESP32 may broadcast:

```json
"riskValid": false,

"risk": {
  "head": -1,
  "shoulders": -1,
  "hips": -1,
  "heels": -1
}
```

Dashboard logic:

```text
if riskValid == false:
    ignore the -1 values
    show "Waiting for assessment"
```

Do not display:

```text
Head: -1%
```

---

# 14. Highest-Risk Region

Example:

```json
"highestRisk": {
  "zone": "HIPS",
  "score": 42,
  "level": "MEDIUM"
}
```

## `zone`

Expected values after valid inference:

```text
HEAD
SHOULDERS
HIPS
HEELS
```

Before valid inference:

```text
NONE
```

---

## `score`

Range after valid assessment:

```text
0 ... 100
```

Before assessment it may be:

```text
-1
```

---

## `level`

Expected values after valid inference:

```text
LOW
MEDIUM
HIGH
```

Before valid inference:

```text
WAITING
```

Recommended UI:

```text
Highest Risk
HIPS

Risk Score
42%

Risk Level
MEDIUM
```

Dashboard rule:

```text
if riskValid == false:
    highestRisk.zone  -> ignore / NONE
    highestRisk.score -> ignore
    highestRisk.level -> WAITING
```

---

# 15. Avoid-Return State

Example:

```json
"avoidReturn": {
  "head": 0,
  "shoulders": 0,
  "hips": 0,
  "heels": 0
}
```

Values:

```text
0 = no active avoid-return condition
1 = active avoid-return condition
```

The current firmware reserves this field for the future forbidden-position / avoid-return feature.

At present the xG26 sends:

```text
0
```

for these flags until the forbidden-position state machine is implemented.

Dashboard should already support this field so the UI does not need to change later.

Example future UI:

```text
ALERT
Avoid returning pressure to Hips
```

---

# 16. ESP32 Uptime

Example:

```json
"uptime": 1217
```

Type:

```text
integer
```

Unit:

```text
seconds
```

Meaning:

Approximate time since the ESP32 booted.

Do not use this value as wall-clock time.

Do not display it as the patient's position duration.

The patient's position duration is:

```text
positionDuration
```

The ESP32 uptime is useful for diagnostics, reset detection, and service information.

---

# 17. Complete Example Before Risk Threshold

Example:

```json
{
  "protocol": 1,
  "deviceId": "VS-BED-001",
  "bed": 1,

  "position": "CENTER",
  "positionDuration": 23,

  "plates": {
    "head": 5,
    "shoulders": 5,
    "hips": 4,
    "heels": 5
  },

  "fsr": [5, 5, 5, 5, 4, 4, 5, 5],

  "riskValid": false,

  "risk": {
    "head": -1,
    "shoulders": -1,
    "hips": -1,
    "heels": -1
  },

  "highestRisk": {
    "zone": "NONE",
    "score": -1,
    "level": "WAITING"
  },

  "avoidReturn": {
    "head": 0,
    "shoulders": 0,
    "hips": 0,
    "heels": 0
  },

  "uptime": 500
}
```

Dashboard should show:

```text
Bed 01
Device: VS-BED-001

Status: LIVE

Position:
CENTER

Current Position Duration:
00:23

Assessment:
Waiting for assessment

Head Risk:       --
Shoulders Risk:  --
Hips Risk:       --
Heels Risk:      --
```

---
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

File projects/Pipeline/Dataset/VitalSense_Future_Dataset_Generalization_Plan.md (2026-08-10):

# VitalSense Future Dataset Collection Plan
## Generalizing FSR Calibration and Pressure-Risk Model Across People

**Document purpose:** Define how future VitalSense datasets should be collected so that FSR calibration and the pressure-risk model generalize across different people, body regions, postures, sessions, and hardware variation.

---

# 1. Goal

The current model and calibration were developed using data from a limited subject set.

Future data collection should make the system more robust across:
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

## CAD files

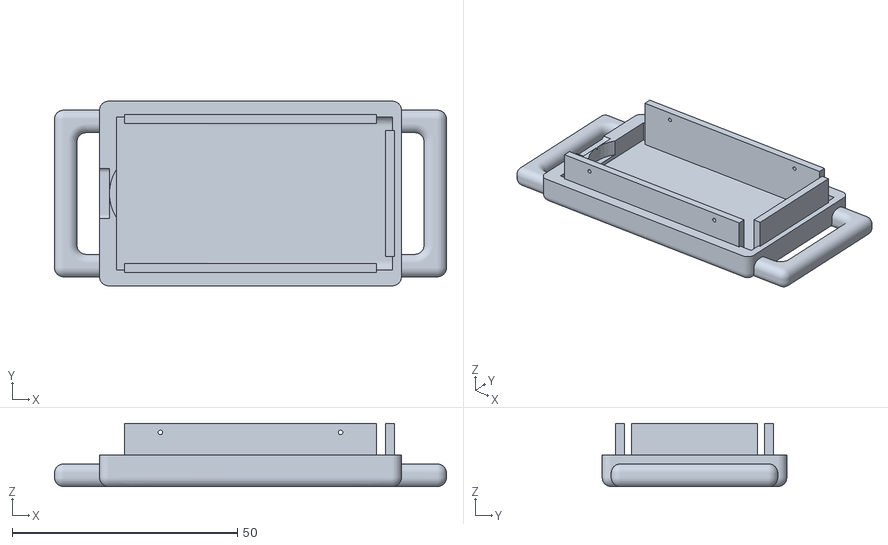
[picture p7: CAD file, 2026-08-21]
resources/Modules 3d Model/Module 1/module1(base).stl
87.0 x 41.0 x 14.0

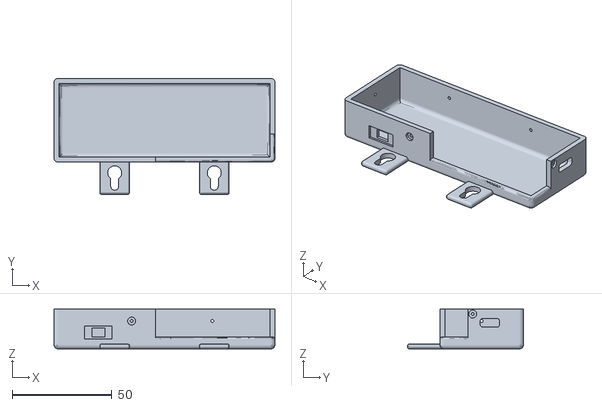
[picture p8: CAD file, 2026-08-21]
resources/Modules 3d Model/Module 2/module2(base).stl
111.0 x 58.2 x 20.0

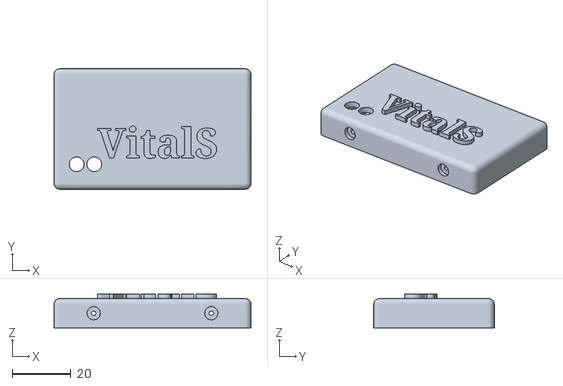
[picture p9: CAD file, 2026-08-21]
resources/Modules 3d Model/Module 1/module1(upper).stl
67.0 x 41.0 x 11.5

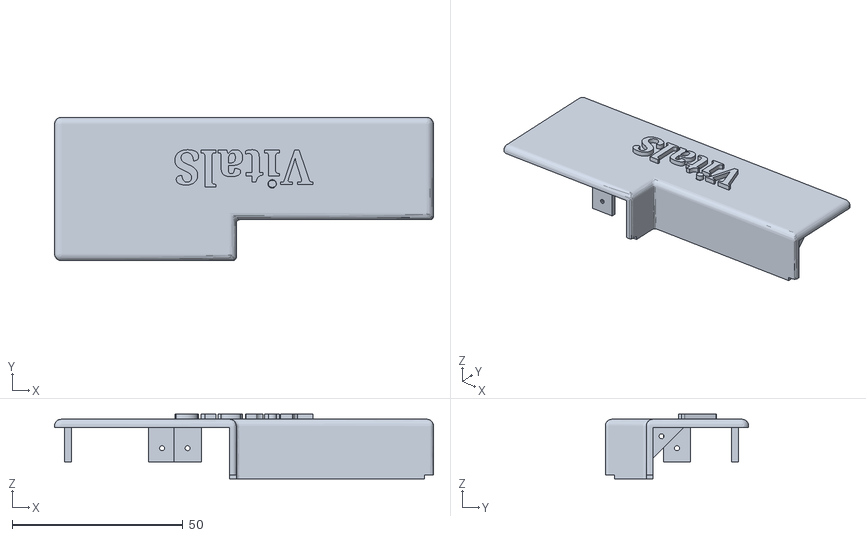
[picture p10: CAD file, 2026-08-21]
resources/Modules 3d Model/Module 2/module2(upper).stl
111.0 x 42.0 x 19.0

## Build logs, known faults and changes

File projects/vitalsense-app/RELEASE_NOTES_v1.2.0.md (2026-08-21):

# VitalSense Caregiver Dashboard v1.2.0

Release date: August 21, 2026

This release adds in-app Wi-Fi credential provisioning for compatible VitalSense ESP32 devices. Caregivers can now configure, change, verify, or clear an ESP32 Wi-Fi connection from the Android app without a separate setup utility.

## Highlights

- Added a guided **Set Up VitalSense** flow using a temporary Bluetooth Low Energy connection.
- Added nearby VitalSense device scanning, explicit device selection, signal-strength labels, and guarded device filtering.
- Added SSID and password entry, including support for open Wi-Fi networks.
- Added detection of an ESP32's existing Wi-Fi configuration through the `STATUS` command.
- Added options to keep the current connection, change networks, or remove stored credentials with `CLEAR`.
- Added live setup progress for BLE connection, GATT service discovery, credential transmission, and ESP32 Wi-Fi connection.
- Added ESP32-reported SSID and IP display after a successful connection.
- Added end-to-end verification: setup completes only after a matching VitalSense UDP packet is received from the provisioned device.
- Added setup entry points from both the empty dashboard state and **Settings > Device Connectivity**.

## Reliability and Recovery

- Added a 10-second BLE scan window and a 15-second BLE connection timeout.
- Added an 8-second timeout to each characteristic write.
- Added a 45-second timeout while waiting for the ESP32 to finish joining Wi-Fi.
- Added a 20-second UDP discovery window after Wi-Fi connects, with **Keep Listening** and **Configure Wi-Fi Again** actions.
- Added retry handling for incorrect credentials without requiring another BLE scan while the setup connection remains active.
- Added recovery screens for Bluetooth disabled, BLE unsupported, permission denied, lost BLE connection, missing GATT services or characteristics, malformed ESP32 responses, and Wi-Fi failures.
- Added strict status parsing for successful, connecting, failed, disconnected, and unconfigured ESP32 states.
- Added source-IP matching so UDP traffic from another VitalSense bed does not complete the selected device's setup flow.
- Preserved explicit multi-device selection throughout provisioning to prevent configuring the wrong bed.

## Credential Privacy

- Wi-Fi passwords are not stored in the provisioning provider or written to application logs.
- The password input is cleared immediately after the BLE transport operation finishes.
- BLE is disconnected after setup; ongoing monitoring continues over Wi-Fi and UDP.
- Clearing credentials requires caregiver confirmation before the app sends the `CLEAR` command.

## Android Integration

- Added Android 12+ Bluetooth Scan and Bluetooth Connect permission support.
- Added legacy Bluetooth and Location permissions for BLE scanning on older Android versions.
- BLE remains an optional hardware feature for installing and using the monitoring dashboard, but is required for in-app ESP32 Wi-Fi setup.
- Added user actions to enable Bluetooth and open app permission settings when setup cannot continue.

## ESP32 Firmware Compatibility

The ESP32 firmware must expose the VitalSense provisioning service and all required characteristics:

| Purpose | UUID |
|---|---|
| Provisioning service | `7a0a0101-5b8a-4f4c-9d1d-8b4e3d7a1000` |
| SSID write | `7a0a0102-5b8a-4f4c-9d1d-8b4e3d7a1000` |
| Password write | `7a0a0103-5b8a-4f4c-9d1d-8b4e3d7a1000` |
| Command write | `7a0a0104-5b8a-4f4c-9d1d-8b4e3d7a1000` |
| Status notification | `7a0a0105-5b8a-4f4c-9d1d-8b4e3d7a1000` |

Supported app commands are `STATUS`, `CONNECT`, and `CLEAR`. Supported ESP32 status notifications are:

- `NO_CREDENTIALS`
- `SSID_RECEIVED`
- `PASSWORD_RECEIVED`
- `CONNECTING|<ssid>`
- `CONNECTED|<ssid>|<ip-address>`
- `FAILED|<reason>`
- `DISCONNECTED|<ssid>`

See the [README](README.md#esp32-firmware-contract) for the complete write order, discovery rules, expected characteristic capabilities, and setup instructions.

## Upgrade Notes

- Update the ESP32 firmware to implement the provisioning GATT contract before using the new setup screen.
- For the most reliable scan result, advertise the provisioning service UUID. Firmware may also advertise a supported name: `VitalSense`, `VitalSense-*`, or `VS-*`.
- The phone and ESP32 must be on the same Wi-Fi network for UDP monitoring after provisioning.
- Existing UDP telemetry remains on VitalSense Protocol v1 and port `5005`; the BLE feature does not replace the monitoring transport.

## Verification

Automated coverage now verifies:

- Provisioning a fresh device over BLE and completing only after UDP discovery.
- Retrying after an incorrect password without rescanning.
- Ignoring UDP packets from a different source IP.
- Keeping the explicitly selected bed as the provisioning target.
- Preserving existing working credentials after a `STATUS` response.
- Parsing every supported status response and rejecting malformed payloads.

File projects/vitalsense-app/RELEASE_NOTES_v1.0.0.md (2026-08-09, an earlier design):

# 🚀 VitalSense Caregiver Dashboard v1.0.0

Welcome to the initial official release of the **VitalSense Caregiver Dashboard** Android application! 🩺

This release provides real-time, non-invasive patient pressure monitoring, body posture tracking, and ML-driven pressure injury risk assessment directly over local Wi-Fi.

---

## ✨ Key Highlights

- ⚡ **Zero-Config Auto-Discovery**: Automatically discovers and streams live data from ESP32 bed units broadcasting over UDP port `5005`.
- 🛏️ **Real-Time Bed & Connection Monitor**: Live connection badges (`LIVE`, `STALE`, `OFFLINE`) with dynamic heartbeats and packet delay indicators.
- 🧘 **Posture & Duration Tracking**: Monitors orientation (`CENTER/BACK`, `LEFT`, `RIGHT`) and posture duration counters.
- ⚠️ **Anatomical Risk Assessment**: Visual circular gauges for 4 anatomical regions (Head, Shoulders, Hips, Heels) with highest-risk highlights and 60s threshold progression.
- 📊 **Raw Sensor Array & Plate ADC Grid**: 8-channel raw FSR pressure visualizer (ADC 0–4095) with 4-zone averaged plate progress bars.
- 🔧 **Engineering Diagnostics**: Technical telemetry screen displaying ESP32 uptime, protocol version, source IP, raw ADC values, and Avoid-Return alerts.

---

## 🛠️ Technical Improvements & Stability Fixes

- **Robust JSON Parsing**: Handles both integer and double JSON values from ESP32 edge firmware with null-safe fallbacks across all payload sub-objects.
- **Source IP Forwarding**: Accurately tracks source IP addresses across broadcast packets for multi-bed diagnostic identification.
- **Race Condition Prevention**: Hardened device lookup state to prevent null reference crashes when devices connect or disconnect.
- **Strict Lint Compliance**: Clean code base passing `flutter analyze` with 0 warnings/errors under Flutter standard lint rules.

---

## 📦 Download Assets

| Asset | Description | Size |
|---|---|---|
| 📱 `app-release.apk` | Production Release APK (ARM64 / Universal) | ~44.7 MB |

---

### 📋 Installation Instructions
1. Download `app-release.apk` onto your Android device.
2. Allow installation from unknown sources if prompted.
3. Connect your mobile device to the same Wi-Fi network as the VitalSense ESP32 units.
4. Launch **VitalSense** — the dashboard will automatically discover active bed streams on port `5005`.

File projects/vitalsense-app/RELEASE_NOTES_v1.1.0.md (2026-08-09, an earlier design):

# 🚀 VitalSense Caregiver Dashboard v1.1.0

Welcome to the **v1.1.0** update of the **VitalSense Caregiver Dashboard** Android application! This release focuses on stability enhancements, performance optimizations, and quality-of-life improvements based on caregiver feedback.

---

## ✨ New Features & Enhancements

- 🔔 **Customizable Alert Thresholds**: Configure per-region pressure injury risk thresholds (Head, Shoulders, Hips, Heels) with adjustable time-to-alert durations (30s–120s).
- 📱 **Landscape Mode Support**: Full landscape orientation support for tablet-mounted dashboard stations with responsive layout reflow.
- 🌙 **Dark/Light Theme Toggle**: System-following theme with manual override in Settings for improved visibility in low-light care environments.
- 📈 **Historical Trend Viewer**: New 24-hour pressure trend charts per anatomical region with peak/average indicators and export capability.
- 🔊 **Audible Alert Options**: Configurable notification sounds (chime, vibration, silent) with per-severity assignment (Warning/Critical).
- 🌐 **Multi-Language Support**: Added Spanish (ES) and French (FR) localizations with RTL layout preparation.

---

## 🛠️ Technical Improvements & Stability Fixes

- **Performance Optimization**: Reduced CPU usage by ~35% during continuous streaming via frame-batching and optimized ADC rendering pipeline.
- **Memory Leak Fixes**: Resolved subscription leaks in `DeviceStreamManager` and `RiskAssessmentEngine` during rapid device connect/disconnect cycles.
- **Network Resilience**: Improved UDP packet reassembly with 200ms jitter buffer; added automatic reconnection with exponential backoff (1s→30s).
- **JSON Parsing Hardening**: Extended null-safe parsing to new telemetry fields (battery %, firmware build hash, sensor calibration metadata).
- **Flutter 3.24 Migration**: Updated to Flutter 3.24.4 with Dart 3.5.3; resolved deprecation warnings and enabled `wasm` compilation target.
- **Strict Lint Compliance**: Maintains 0 warnings/errors under `flutter analyze` with additional `very_good_analysis` rules enabled.

---

## 🐛 Bug Fixes

- Fixed posture duration counter reset on brief signal loss (<2s)
- Corrected Heels region ADC mapping for ESP32 firmware v2.1+ (channel remap)
- Resolved occasional "STALE" false positives during Wi-Fi roaming
- Fixed landscape keyboard overlay obscuring alert configuration dialog
- Patched APK installation failure on Android 14+ with scoped storage enforcement

---

## 📦 Download Assets

| Asset | Description | Size |
|---|---|---|
| 📱 `app-release-v1.1.0.apk` | Production Release APK (ARM64 / Universal) | ~46.2 MB |
| 📦 `app-release-v1.1.0.aab` | Android App Bundle for Play Store | ~42.8 MB |

---

### 📋 Installation Instructions

1. Download `app-release-v1.1.0.apk` onto your Android device.
2. Allow installation from unknown sources if prompted.
3. Connect your mobile device to the same Wi-Fi network as the VitalSense ESP32 units.
4. Launch **VitalSense** — the dashboard will automatically discover active bed streams on port `5005`.

---

### 🔄 Upgrade Notes from v1.0.0

- **Configuration Migration**: Existing alert thresholds reset to defaults; reconfigure in Settings → Alert Thresholds.
- **Theme Preference**: Defaults to system theme; previous light-only behavior migrated to "Light" manual selection.
- **Data Compatibility**: Historical trend data requires v1.1.0+ firmware on ESP32 units (v2.1+ recommended).

---

**Full Changelog**: [Compare v1.0.0...v1.1.0](https://github.com/your-org/vitalsense-app/compare/v1.0.0...v1.1.0)

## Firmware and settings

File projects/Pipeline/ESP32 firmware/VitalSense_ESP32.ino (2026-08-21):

/*
  VitalSense ESP32-C3 - LEAN BUILD

  Purpose
  -------
  Keeps only the functions needed for the final xG26 architecture:

  1. Read 8 FSR sensors through 74HC4051/CD4051.
  2. Average them into Head / Shoulders / Hips / Heels.
  3. Act as BLE peripheral for the EFR32xG26.
  4. On command 0x01, perform a fresh FSR scan and notify all 8 FSR values.
  5. Receive four EFR32 ML risk packets:
       [0x02, bodyId, risk0to100, avoidReturnFlag]
  6. Receive EFR32 posture / summary state:
       [0x03, position, duration_u32_le, riskValid,
        highestZone, highestScore, riskLevel]
  7. Provision local Wi-Fi credentials from a phone over BLE and retain them
     in ESP32 NVS across reboots.
  8. Broadcast the complete VitalSense Protocol v1 JSON over UDP.
  9. Drive the active-low GPIO 7 system-status LED.

  Size reductions compared with the previous sketch
  -------------------------------------------------
  - NimBLE instead of the larger classic Arduino BLE classes.
  - ArduinoJson removed.
  - ESP32 local pressure-risk algorithm removed.
  - Pressure-duration and movement tracking removed.
  - BLE2902 object removed; NimBLE creates CCCD automatically.
  - Logging reduced.

  BLE protocol
  ------------
  Name:
    VitalSense-ESP32C3

  Service:
    7a0a0001-5b8a-4f4c-9d1d-8b4e3d7a1000

  RX (EFR32 -> ESP32):
    7a0a0002-5b8a-4f4c-9d1d-8b4e3d7a1000

  TX (ESP32 -> EFR32):
    7a0a0003-5b8a-4f4c-9d1d-8b4e3d7a1000

  EFR32 -> ESP32:
    01
    02 BODY RISK FLAG
    03 POSITION DURATION_U32_LE RISK_VALID HIGHEST_ZONE HIGHEST_SCORE LEVEL

  ESP32 -> EFR32:
    81 08 FSR0_L FSR0_H ... FSR7_L FSR7_H

  Phone Wi-Fi provisioning BLE service:
    Service: 7a0a0101-5b8a-4f4c-9d1d-8b4e3d7a1000
    SSID:    7a0a0102-5b8a-4f4c-9d1d-8b4e3d7a1000  (WRITE UTF-8)
    Password:7a0a0103-5b8a-4f4c-9d1d-8b4e3d7a1000  (WRITE UTF-8)
    Command: 7a0a0104-5b8a-4f4c-9d1d-8b4e3d7a1000  (WRITE)
             CONNECT / STATUS / CLEAR
    Status:  7a0a0105-5b8a-4f4c-9d1d-8b4e3d7a1000  (READ + NOTIFY)

  Target library:
    NimBLE-Arduino 2.x
*/

#include <Arduino.h>
#include <WiFi.h>
#include <WiFiUdp.h>
#include <Preferences.h>
#include <NimBLEDevice.h>

/* ============================================================
   USER CONFIG
   ============================================================ */

/*
 * Wi-Fi credentials are provisioned from the phone over BLE and saved in
 * ESP32 NVS. Nothing is hard-coded here anymore.
 */
static const uint16_t UDP_PORT = 5005;

static const uint32_t WIFI_PROVISION_TIMEOUT_MS = 20000;
static const size_t WIFI_SSID_MAX_LEN = 32;
static const size_t WIFI_PASSWORD_MAX_LEN = 64;

/*
 * VitalSense Protocol v1 identity.
 * Change DEVICE_ID / BED_ID for each deployed bed.
 */
static const uint8_t PROTOCOL_VERSION = 1;
static const char* DEVICE_ID = "VS-BED-001";
static const uint8_t BED_ID = 1;

/* ============================================================
   FSR / MUX
   ============================================================ */

#define MUX_SIG 0
#define MUX_S0  4
#define MUX_S1  3
#define MUX_S2  2
#define MUX_INH 5

#define STATUS_LED 7

static const uint8_t FSR_COUNT = 8;
static const uint8_t PLATE_COUNT = 4;

static const uint16_t MUX_SETTLE_MS = 3;
static const uint8_t SAMPLES_PER_READ = 8;
static const uint16_t SAMPLE_DELAY_MS = 1;

static const uint32_t SENSOR_SCAN_INTERVAL_MS = 250;
static const uint32_t UDP_SEND_INTERVAL_MS = 1000;
static const uint32_t WIFI_RETRY_INTERVAL_MS = 5000;
static const uint32_t STATUS_LED_BLINK_INTERVAL_MS = 500;

static uint16_t fsrRaw[FSR_COUNT] = {0};
static uint16_t plateAverage[PLATE_COUNT] = {0};

static uint32_t lastSensorScanMs = 0;
static uint32_t lastUdpSendMs = 0;
static uint32_t lastWifiRetryMs = 0;

/* ============================================================
   BLE
   ============================================================ */

#define BLE_DEVICE_NAME "VitalSense-ESP32C3"

#define BLE_SERVICE_UUID "7a0a0001-5b8a-4f4c-9d1d-8b4e3d7a1000"
#define BLE_RX_UUID      "7a0a0002-5b8a-4f4c-9d1d-8b4e3d7a1000"
#define BLE_TX_UUID      "7a0a0003-5b8a-4f4c-9d1d-8b4e3d7a1000"

/*
 * Phone Wi-Fi provisioning service.
 *
 * The service itself does not need to be included in the advertising packet;
 * the phone can find the unit by BLE_DEVICE_NAME, connect, then discover it.
 * This keeps the legacy advertising packet small while the existing xG26
 * service UUID remains advertised.
 */
#define WIFI_PROV_SERVICE_UUID "7a0a0101-5b8a-4f4c-9d1d-8b4e3d7a1000"
#define WIFI_PROV_SSID_UUID    "7a0a0102-5b8a-4f4c-9d1d-8b4e3d7a1000"
#define WIFI_PROV_PASS_UUID    "7a0a0103-5b8a-4f4c-9d1d-8b4e3d7a1000"
#define WIFI_PROV_CMD_UUID     "7a0a0104-5b8a-4f4c-9d1d-8b4e3d7a1000"
#define WIFI_PROV_STATUS_UUID  "7a0a0105-5b8a-4f4c-9d1d-8b4e3d7a1000"

static const uint8_t BLE_CMD_REQUEST_FSR = 0x01;
static const uint8_t BLE_CMD_RISK_UPDATE = 0x02;
static const uint8_t BLE_CMD_STATE_UPDATE = 0x03;
static const uint8_t BLE_MSG_FSR_RESPONSE = 0x81;

static const uint8_t STATE_PACKET_LENGTH = 10;

static NimBLEServer* bleServer = nullptr;
static NimBLECharacteristic* bleRx = nullptr;
static NimBLECharacteristic* bleTx = nullptr;

static NimBLECharacteristic* wifiProvSsid = nullptr;
static NimBLECharacteristic* wifiProvPass = nullptr;
static NimBLECharacteristic* wifiProvCmd = nullptr;
static NimBLECharacteristic* wifiProvStatus = nullptr;

/*
 * A phone can also connect to this BLE server, so a generic server connection
 * is not the same thing as the EFR32/xG26 connection. We mark the EFR32 link
 * active only when it actually writes the VitalSense RX characteristic.
 */
static volatile bool efrBleConnected = false;
static volatile uint16_t efrConnHandle = 0xFFFFU;
static volatile bool bleFsrRequestPending = false;

/* ============================================================
   EFR RISK STATE
   ============================================================ */

struct EfrRiskState {
  uint8_t risk;
  bool avoidReturn;
  bool valid;
};

/*
 * Active risk state exposed to UDP.
 * New 0x02 packets are first staged and are committed atomically only when
 * the following 0x03 summary packet arrives. This prevents the dashboard/app
 * from seeing a mixture of old and new body risks while the four BLE writes
 * are still in progress.
 */
static EfrRiskState efrRisk[PLATE_COUNT] = {};
static EfrRiskState pendingEfrRisk[PLATE_COUNT] = {};
static uint8_t pendingRiskMask = 0U;

struct EfrSummaryState {
  uint8_t position;             // 0=CENTER, 1=LEFT, 2=RIGHT
  uint32_t positionDurationSec;
  bool riskValid;
  uint8_t highestRiskZone;      // 0=none, 1=Head, 2=Shoulders, 3=Hips, 4=Heels
  uint8_t highestRiskScore;     // 0..100
  uint8_t riskLevel;            // 0=LOW, 1=MEDIUM, 2=HIGH
  bool valid;                   // received at least one 0x03 packet
};

static EfrSummaryState efrSummary = {};

static portMUX_TYPE sharedMux = portMUX_INITIALIZER_UNLOCKED;

/* ============================================================
   WIFI / UDP
   ============================================================ */

static WiFiUDP udp;
static Preferences wifiPreferences;

static bool wifiWasConnected = false;
static volatile bool udpHasTransmitted = false;

/* Saved/active Wi-Fi credentials. */
static char wifiSsid[WIFI_SSID_MAX_LEN + 1] = {0};
static char wifiPassword[WIFI_PASSWORD_MAX_LEN + 1] = {0};
static bool wifiCredentialsAvailable = false;

/* Credentials staged by the phone over BLE. */
static char stagedWifiSsid[WIFI_SSID_MAX_LEN + 1] = {0};
static char stagedWifiPassword[WIFI_PASSWORD_MAX_LEN + 1] = {0};
static volatile bool stagedSsidReceived = false;
static volatile bool stagedPasswordReceived = false;
static volatile bool wifiConnectRequested = false;
static volatile bool wifiClearRequested = false;
static volatile bool wifiStatusRequested = false;

/* Candidate connection is tested before replacing the saved credentials. */
static bool wifiProvisionAttemptActive = false;
static uint32_t wifiProvisionStartedMs = 0;

/* ============================================================
   BASIC HELPERS
   ============================================================ */

static void setStatusLed(bool on)
{
  digitalWrite(STATUS_LED, on ? LOW : HIGH);
}

static IPAddress getSubnetBroadcastAddress()
{
  const IPAddress ip = WiFi.localIP();
  const IPAddress mask = WiFi.subnetMask();

  IPAddress broadcast;

  for (uint8_t i = 0; i < 4; i++) {
    broadcast[i] =
        (uint8_t)(ip[i] | (uint8_t)(~mask[i]));
  }

  return broadcast;
}

static const char* positionName(uint8_t position)
{
  switch (position) {
    case 1: return "LEFT";
    case 2: return "RIGHT";
    case 0:
    default:
      return "CENTER";
  }
}

static const char* zoneName(uint8_t zone)
{
  switch (zone) {
    case 1: return "HEAD";
    case 2: return "SHOULDERS";
    case 3: return "HIPS";
    case 4: return "HEELS";
    default:
      return "NONE";
  }
}

static const char* riskLevelName(uint8_t level)
{
  switch (level) {
    case 1: return "MEDIUM";
    case 2: return "HIGH";
    case 0:
    default:
      return "LOW";
  }
}

static uint32_t getU32LE(const uint8_t* src)
{
  return ((uint32_t)src[0])
      | ((uint32_t)src[1] << 8U)
      | ((uint32_t)src[2] << 16U)
      | ((uint32_t)src[3] << 24U);
}

static void selectMuxChannel(uint8_t channel)
{
  digitalWrite(MUX_S0, bitRead(channel, 0));
  digitalWrite(MUX_S1, bitRead(channel, 1));
  digitalWrite(MUX_S2, bitRead(channel, 2));
}

static uint16_t readMuxChannel()
{
  delay(MUX_SETTLE_MS);

  /* Discard first conversion after switching the MUX. */
  (void)analogRead(MUX_SIG);

  uint32_t total = 0;

  for (uint8_t i = 0; i < SAMPLES_PER_READ; i++) {
    total += (uint16_t)analogRead(MUX_SIG);

    if (SAMPLE_DELAY_MS != 0) {
      delay(SAMPLE_DELAY_MS);
    }
  }

  return (uint16_t)(total / SAMPLES_PER_READ);
}

static void scanAllSensors()
{
  for (uint8_t i = 0; i < FSR_COUNT; i++) {
    selectMuxChannel(i);
    fsrRaw[i] = readMuxChannel();
  }

  plateAverage[0] =
      (uint16_t)(((uint32_t)fsrRaw[0] + fsrRaw[1]) / 2U);

  plateAverage[1] =
      (uint16_t)(((uint32_t)fsrRaw[2] + fsrRaw[3]) / 2U);

  plateAverage[2] =
      (uint16_t)(((uint32_t)fsrRaw[4] + fsrRaw[5]) / 2U);

  plateAverage[3] =
      (uint16_t)(((uint32_t)fsrRaw[6] + fsrRaw[7]) / 2U);
}

static void putU16LE(uint8_t* dst, uint16_t value)
{
  dst[0] = (uint8_t)(value & 0xFFU);
  dst[1] = (uint8_t)((value >> 8U) & 0xFFU);
}

/* ============================================================
   WIFI CREDENTIAL STORAGE / BLE PROVISIONING HELPERS
   ============================================================ */

static void setProvisioningStatus(const char* status)
{
  if (wifiProvStatus == nullptr) {
    return;
  }

  wifiProvStatus->setValue(status);
  wifiProvStatus->notify();

  Serial.print("[WiFi Prov] ");
  Serial.println(status);
}

static void publishCurrentWifiStatus()
{
  char status[128];

  if (WiFi.status() == WL_CONNECTED) {
    snprintf(
        status,
        sizeof(status),
        "CONNECTED|%s|%s",
        WiFi.SSID().c_str(),
        WiFi.localIP().toString().c_str());
  } else if (wifiProvisionAttemptActive) {
    snprintf(
        status,
        sizeof(status),
        "CONNECTING|%s",
        stagedWifiSsid);
  } else if (wifiCredentialsAvailable) {
    snprintf(
        status,
        sizeof(status),
        "DISCONNECTED|%s",
        wifiSsid);
  } else {
    snprintf(status, sizeof(status), "NO_CREDENTIALS");
  }

  setProvisioningStatus(status);
}

static bool isValidProvisionedCredentials(const char* ssid,
                                          const char* password)
{
  const size_t ssidLen = strlen(ssid);
  const size_t passwordLen = strlen(password);

  if ((ssidLen < 1U) || (ssidLen > WIFI_SSID_MAX_LEN)) {
    return false;
  }

  /* Empty password = open network. WPA/WPA2 PSK is normally 8..63 chars;
     64 is also accepted for a raw hexadecimal PSK. */
  if ((passwordLen != 0U)
      && ((passwordLen < 8U)
          || (passwordLen > WIFI_PASSWORD_MAX_LEN))) {
    return false;
  }

  return true;
}

static void loadWifiCredentials()
{
  wifiSsid[0] = '\0';
  wifiPassword[0] = '\0';
  wifiCredentialsAvailable = false;

  if (!wifiPreferences.begin("vitalwifi", true)) {
    Serial.println("[WiFi] NVS open failed");
    return;
  }

  String storedSsid =
      wifiPreferences.getString("ssid", "");

  String storedPassword =
      wifiPreferences.getString("pass", "");

  wifiPreferences.end();

  if (!isValidProvisionedCredentials(
          storedSsid.c_str(),
          storedPassword.c_str())) {
    Serial.println("[WiFi] No valid saved credentials");
    return;
  }

  strlcpy(
      wifiSsid,
      storedSsid.c_str(),
      sizeof(wifiSsid));

  strlcpy(
      wifiPassword,
      storedPassword.c_str(),
      sizeof(wifiPassword));

  wifiCredentialsAvailable = true;

  Serial.print("[WiFi] Loaded saved SSID: ");
  Serial.println(wifiSsid);
}

static bool saveWifiCredentials(const char* ssid,
                                const char* password)
{
  if (!wifiPreferences.begin("vitalwifi", false)) {
    return false;
  }

  const size_t ssidWritten =
      wifiPreferences.putString("ssid", ssid);

  const size_t passwordWritten =
      wifiPreferences.putString("pass", password);

  wifiPreferences.end();

  if ((ssidWritten == 0U) || (passwordWritten == 0U)) {
    return false;
  }

  strlcpy(wifiSsid, ssid, sizeof(wifiSsid));
  strlcpy(wifiPassword, password, sizeof(wifiPassword));
  wifiCredentialsAvailable = true;

  return true;
}

static void clearWifiCredentials()
{
  if (wifiPreferences.begin("vitalwifi", false)) {
    wifiPreferences.clear();
    wifiPreferences.end();
  }

  wifiSsid[0] = '\0';
  wifiPassword[0] = '\0';
  stagedWifiSsid[0] = '\0';
  stagedWifiPassword[0] = '\0';

  wifiCredentialsAvailable = false;
  stagedSsidReceived = false;
  stagedPasswordReceived = false;
  wifiProvisionAttemptActive = false;

  WiFi.disconnect(true, false);
  udp.stop();
  wifiWasConnected = false;
  udpHasTransmitted = false;

  setProvisioningStatus("CLEARED");
}

static bool copyBleTextToBuffer(NimBLECharacteristic* characteristic,
                                char* destination,
                                size_t destinationSize)
{
  NimBLEAttValue value = characteristic->getValue();
  const size_t len = value.size();

  if ((destinationSize == 0U) || (len >= destinationSize)) {
    return false;
  }

  if (len != 0U) {
    memcpy(destination, value.data(), len);
  }

  destination[len] = '\0';
  return true;
}

class WifiSsidCallbacks : public NimBLECharacteristicCallbacks {
  void onWrite(NimBLECharacteristic* characteristic,
               NimBLEConnInfo& connInfo) override
  {
    (void)connInfo;

    if (!copyBleTextToBuffer(
            characteristic,
            stagedWifiSsid,
            sizeof(stagedWifiSsid))) {
      stagedSsidReceived = false;
      setProvisioningStatus("ERROR|SSID_TOO_LONG");
      return;
    }

    stagedSsidReceived =
        (strlen(stagedWifiSsid) != 0U);

    setProvisioningStatus(
        stagedSsidReceived
        ? "SSID_RECEIVED"
        : "ERROR|SSID_EMPTY");
  }
};

class WifiPasswordCallbacks : public NimBLECharacteristicCallbacks {
  void onWrite(NimBLECharacteristic* characteristic,
               NimBLEConnInfo& connInfo) override
  {
    (void)connInfo;

    if (!copyBleTextToBuffer(
            characteristic,
            stagedWifiPassword,
            sizeof(stagedWifiPassword))) {
      stagedPasswordReceived = false;
      setProvisioningStatus("ERROR|PASSWORD_TOO_LONG");
      return;
    }

    /* Empty is valid for an open Wi-Fi network. */
    stagedPasswordReceived = true;
    setProvisioningStatus("PASSWORD_RECEIVED");
  }
};

class WifiCommandCallbacks : public NimBLECharacteristicCallbacks {
  void onWrite(NimBLECharacteristic* characteristic,
               NimBLEConnInfo& connInfo) override
  {
    (void)connInfo;

    char command[24];

    if (!copyBleTextToBuffer(
            characteristic,
            command,
            sizeof(command))) {
      setProvisioningStatus("ERROR|BAD_COMMAND");
      return;
    }

    if (strcmp(command, "CONNECT") == 0) {
      wifiConnectRequested = true;
      return;
    }

    if (strcmp(command, "CLEAR") == 0) {
      wifiClearRequested = true;
      return;
    }

    if (strcmp(command, "STATUS") == 0) {
      wifiStatusRequested = true;
      return;
    }

    setProvisioningStatus("ERROR|UNKNOWN_COMMAND");
  }
};

/* ============================================================
   BLE CALLBACKS
   ============================================================ */

class VitalSenseServerCallbacks : public NimBLEServerCallbacks {
  void onConnect(NimBLEServer* server,
                 NimBLEConnInfo& connInfo) override
  {
    Serial.print("[BLE] Client connected, handle=");
    Serial.println(connInfo.getConnHandle());

    /*
     * Continue advertising so the second client (phone or EFR32) can also
     * connect. NimBLE-Arduino defaults to multiple simultaneous connections.
     */
    if (server->getConnectedCount() < 2U) {
      NimBLEDevice::getAdvertising()->start();
    }
  }

  void onDisconnect(NimBLEServer* server,
                    NimBLEConnInfo& connInfo,
                    int reason) override
  {
    (void)server;
    (void)reason;

    if (connInfo.getConnHandle() == efrConnHandle) {
      efrBleConnected = false;
      efrConnHandle = 0xFFFFU;
      udpHasTransmitted = false;

      Serial.println("[BLE] EFR32/xG26 disconnected");
    } else {
      Serial.print("[BLE] Client disconnected, handle=");
      Serial.println(connInfo.getConnHandle());
    }

    /* advertiseOnDisconnect(true) restarts advertising automatically. */
  }
};
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
void loop()
{
  processWifiProvisioning();
  maintainWiFi();

  /*
   * Highest priority:
   * service the xG26 request with a fresh sensor scan.
   */
  processBleRequest();

  const uint32_t now =
      millis();

  /*
   * Keep local values fresh for UDP.
   */
  if ((now - lastSensorScanMs)
      >= SENSOR_SCAN_INTERVAL_MS) {

    lastSensorScanMs =
        now;

    scanAllSensors();

    /*
     * Update the READ value but do not send unsolicited notification.
     */
    uint8_t packet[18];

    packet[0] =
        BLE_MSG_FSR_RESPONSE;

    packet[1] =
        FSR_COUNT;

    for (uint8_t i = 0; i < FSR_COUNT; i++) {
      putU16LE(
          &packet[2U + (i * 2U)],
          fsrRaw[i]);
    }

    bleTx->setValue(
        packet,
        sizeof(packet));
  }

  if ((now - lastUdpSendMs)
      >= UDP_SEND_INTERVAL_MS) {

    lastUdpSendMs =
        now;

    sendUdpState();
  }

  updateSystemStatusLed();

  delay(2);
}

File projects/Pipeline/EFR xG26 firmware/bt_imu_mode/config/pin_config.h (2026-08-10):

#ifndef PIN_CONFIG_H
#define PIN_CONFIG_H

// $[CMU]
// [CMU]$

// $[LFXO]
// [LFXO]$

// $[KEYSCAN]
// [KEYSCAN]$

// $[PRS.ASYNCH0]
// [PRS.ASYNCH0]$

// $[PRS.ASYNCH1]
// [PRS.ASYNCH1]$

// $[PRS.ASYNCH2]
// [PRS.ASYNCH2]$

// $[PRS.ASYNCH3]
// [PRS.ASYNCH3]$

// $[PRS.ASYNCH4]
// [PRS.ASYNCH4]$

// $[PRS.ASYNCH5]
// [PRS.ASYNCH5]$

// $[PRS.ASYNCH6]
// [PRS.ASYNCH6]$

// $[PRS.ASYNCH7]
// [PRS.ASYNCH7]$

// $[PRS.ASYNCH8]
// [PRS.ASYNCH8]$

// $[PRS.ASYNCH9]
// [PRS.ASYNCH9]$

// $[PRS.ASYNCH10]
// [PRS.ASYNCH10]$

// $[PRS.ASYNCH11]
// [PRS.ASYNCH11]$

// $[PRS.ASYNCH12]
// [PRS.ASYNCH12]$

// $[PRS.ASYNCH13]
// [PRS.ASYNCH13]$

// $[PRS.ASYNCH14]
// [PRS.ASYNCH14]$

// $[PRS.ASYNCH15]
// [PRS.ASYNCH15]$

// $[PRS.SYNCH0]
// [PRS.SYNCH0]$

// $[PRS.SYNCH1]
// [PRS.SYNCH1]$

// $[PRS.SYNCH2]
// [PRS.SYNCH2]$

// $[PRS.SYNCH3]
// [PRS.SYNCH3]$

// $[GPIO]
// GPIO SWV on PA03
#ifndef GPIO_SWV_PORT                           
#define GPIO_SWV_PORT                            SL_GPIO_PORT_A
#endif
#ifndef GPIO_SWV_PIN                            
#define GPIO_SWV_PIN                             3
#endif

// [GPIO]$

// $[TIMER0]
// TIMER0 CC0 on PD07
#ifndef TIMER0_CC0_PORT                         
#define TIMER0_CC0_PORT                          SL_GPIO_PORT_D
#endif
#ifndef TIMER0_CC0_PIN                          
#define TIMER0_CC0_PIN                           7
#endif

// TIMER0 CC1 on PA04
#ifndef TIMER0_CC1_PORT                         
#define TIMER0_CC1_PORT                          SL_GPIO_PORT_A
#endif
#ifndef TIMER0_CC1_PIN                          
#define TIMER0_CC1_PIN                           4
#endif

// TIMER0 CC2 on PB00
#ifndef TIMER0_CC2_PORT                         
#define TIMER0_CC2_PORT                          SL_GPIO_PORT_B
#endif
#ifndef TIMER0_CC2_PIN                          
#define TIMER0_CC2_PIN                           0
#endif

// [TIMER0]$

// $[TIMER1]
// [TIMER1]$

// $[TIMER2]
// [TIMER2]$

// $[TIMER3]
// [TIMER3]$

// $[TIMER4]
// [TIMER4]$

// $[TIMER5]
// [TIMER5]$

// $[TIMER6]
// [TIMER6]$

// $[TIMER7]
// [TIMER7]$

// $[TIMER8]
// [TIMER8]$

// $[TIMER9]
// [TIMER9]$

// $[EUSART1]
// EUSART1 CS on PC00
#ifndef EUSART1_CS_PORT                         
#define EUSART1_CS_PORT                          SL_GPIO_PORT_C
#endif
#ifndef EUSART1_CS_PIN                          
#define EUSART1_CS_PIN                           0
#endif

// EUSART1 RX on PC02
#ifndef EUSART1_RX_PORT                         
#define EUSART1_RX_PORT                          SL_GPIO_PORT_C
#endif
#ifndef EUSART1_RX_PIN                          
#define EUSART1_RX_PIN                           2
#endif

// EUSART1 SCLK on PC01
#ifndef EUSART1_SCLK_PORT                       
#define EUSART1_SCLK_PORT                        SL_GPIO_PORT_C
#endif
#ifndef EUSART1_SCLK_PIN                        
#define EUSART1_SCLK_PIN                         1
#endif

// EUSART1 TX on PC03
#ifndef EUSART1_TX_PORT                         
#define EUSART1_TX_PORT                          SL_GPIO_PORT_C
#endif
#ifndef EUSART1_TX_PIN                          
#define EUSART1_TX_PIN                           3
#endif

// [EUSART1]$

// $[EUSART2]
// [EUSART2]$

// $[EUSART3]
// [EUSART3]$

// $[USART0]
// USART0 CTS on PA09
#ifndef USART0_CTS_PORT                         
#define USART0_CTS_PORT                          SL_GPIO_PORT_A
#endif
#ifndef USART0_CTS_PIN                          
#define USART0_CTS_PIN                           9
#endif

// USART0 RTS on PA08
#ifndef USART0_RTS_PORT                         
#define USART0_RTS_PORT                          SL_GPIO_PORT_A
#endif
#ifndef USART0_RTS_PIN                          
#define USART0_RTS_PIN                           8
#endif

// USART0 RX on PA06
#ifndef USART0_RX_PORT                          
#define USART0_RX_PORT                           SL_GPIO_PORT_A
#endif
#ifndef USART0_RX_PIN                           
#define USART0_RX_PIN                            6
#endif

// USART0 TX on PA05
#ifndef USART0_TX_PORT                          
#define USART0_TX_PORT                           SL_GPIO_PORT_A
#endif
#ifndef USART0_TX_PIN                           
#define USART0_TX_PIN                            5
#endif

// [USART0]$

// $[USART1]
// [USART1]$

// $[USART2]
// [USART2]$

// $[I2C1]
// [I2C1]$

// $[I2C2]
// [I2C2]$

// $[I2C3]
// [I2C3]$

// $[LCD]
// [LCD]$

// $[LETIMER0]
// [LETIMER0]$

// $[IADC0]
// [IADC0]$

// $[ACMP0]
// [ACMP0]$

// $[ACMP1]
// [ACMP1]$

// $[VDAC0]
// [VDAC0]$

// $[VDAC1]
// [VDAC1]$

// $[PCNT0]
// [PCNT0]$

// $[I2C0]
// [I2C0]$

// $[EUSART0]
// EUSART0 RX on PB06
#ifndef EUSART0_RX_PORT                         
#define EUSART0_RX_PORT                          SL_GPIO_PORT_B
#endif
#ifndef EUSART0_RX_PIN                          
#define EUSART0_RX_PIN                           6
#endif
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

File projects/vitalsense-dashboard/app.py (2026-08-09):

#!/usr/bin/env python3
# -*- coding: utf-8 -*-
"""
VitalS Application Controller
===============================================================================

This module is the single entry point and orchestration layer for the VitalS
Raspberry Pi kiosk application. It is intentionally "thin": it does not
implement business logic itself, it *coordinates* the existing manager
classes (ConfigManager, BackendManager, FrontendManager) and the
ui.splash.SplashScreen UI component through well-defined, narrow interfaces.

NOTE ON THE DASHBOARD WINDOW: the dashboard is intentionally NOT a separate
ui.dashboard module at this stage. The Gtk.Window + WebKit2.WebView pair is
constructed directly inside this controller (see `_build_dashboard_window`
below) to keep the number of moving parts minimal while the application is
still stabilizing. Once the app is stable, `_build_dashboard_window` can be
lifted verbatim into a `ui/dashboard.py` module and injected back in via
`dashboard_factory` -- nothing else in this file would need to change.

Responsibilities of VitalSApplication (and only these):
    1. Read config.json                    -> ConfigManager
    2. Show the splash screen               -> ui.splash.SplashScreen
    3. Start the backend (UDP server)       -> core.backend_manager.BackendManager
    4. Start the frontend (http.server)     -> core.frontend_manager.FrontendManager
    5. Poll http://127.0.0.1:8080 until it responds (non-blocking, no time.sleep)
    6. Open the dashboard in a WebKit2 WebView (built inline, see note above)
    7. Handle clean shutdown (SIGINT/SIGTERM, window close, fatal errors)
    8. Stop backend + frontend on exit
    9. Expose extension points for future modules (Admin Login, Settings,
       Kiosk Mode, Restart, Shutdown, Auto Boot) without requiring this
       controller to be rewritten.

Design principles applied
--------------------------------------------------------------------------
- Single Responsibility : VitalSApplication only orchestrates the lifecycle.
  All actual backend/frontend/process work stays inside the existing manager
  classes. All actual widget construction stays inside the ui.* modules.
- Open/Closed            : new lifecycle stages (login, settings, kiosk,
  restart, shutdown, auto-boot) are added by implementing the corresponding
  `on_*` hook / `_transition_to_*` method and wiring it into
  `_LIFECYCLE_TRANSITIONS`, without touching the startup sequence itself.
- Liskov / Interface     : the controller talks to managers/UI only through
  the minimal interface documented in `ASSUMED_INTERFACES` below. As long as
  the concrete classes honor that contract, they are swappable.
- Interface Segregation  : the controller never reaches into manager
  internals; it only calls start()/stop()/is_running().
- Dependency Inversion   : concrete manager/UI classes are injected via
  simple factory callables, so tests or future variants (e.g. a Docker
  backend manager) can be substituted without editing this file.

Assumed public interfaces of existing components
--------------------------------------------------------------------------
These classes already exist in the project and are NOT rewritten here. This
controller is written against the following minimal contract. If the actual
signatures differ, only the small `_instantiate_*` factory methods below
need to be adjusted -- the rest of the orchestration logic is unaffected.

    ConfigManager(config_path: str)
        .load() -> dict                      # parses config.json
        .get(key: str, default=None) -> Any   # optional convenience accessor

    BackendManager()                         # no constructor arguments
        .start() -> None                     # activates venv & starts udp_server.py
        .stop()  -> None                     # terminates the backend process
        .is_running() -> bool

    FrontendManager()                        # no constructor arguments
        .start() -> None                     # starts `python3 -m http.server 8080`
        .stop()  -> None
        .is_running() -> bool

    ui.splash.SplashScreen(Gtk.Window)
        .show_all() / .destroy()

The dashboard window itself is built directly with Gtk.Window + WebKit2.WebView
inside this file (`_build_dashboard_window`) rather than through a ui.dashboard
module -- see the note above.

Future (NOT implemented here, only wired as extension points):
    ui.login.AdminLoginWindow
    ui.settings.SettingsWindow
    Kiosk mode / Shutdown / Restart / Auto Boot system integration
===============================================================================
"""

import os
import sys
import signal
import logging
import threading
import urllib.request
import urllib.error
import json
import subprocess
from logging.handlers import RotatingFileHandler
from http.server import BaseHTTPRequestHandler, ThreadingHTTPServer
from typing import Optional, Callable, Dict, Any

import gi
gi.require_version("Gtk", "3.0")
gi.require_version("WebKit2", "4.1")
from gi.repository import Gtk, GLib, WebKit2, Gdk  # noqa: E402  (must follow gi.require_version)

from core.config_manager import ConfigManager
from core.backend_manager import BackendManager
from core.frontend_manager import FrontendManager
from ui.splash import SplashScreen

# ---------------------------------------------------------------------------
# Future modules -- intentionally NOT imported/implemented yet.
# When they are built, uncomment the imports and fill in the corresponding
# `_transition_to_*` methods below. The lifecycle map at the bottom of this
# file documents exactly where each one plugs in.
# ---------------------------------------------------------------------------
# from ui.login import AdminLoginWindow
# from ui.settings import SettingsWindow


# ---------------------------------------------------------------------------
# Module-level constants
# ---------------------------------------------------------------------------
APP_ROOT: str = os.path.dirname(os.path.abspath(__file__))
CONFIG_PATH: str = os.path.join(APP_ROOT, "config.json")
LOG_DIR: str = os.path.join(APP_ROOT, "logs")
LOG_FILE: str = os.path.join(LOG_DIR, "app.log")
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

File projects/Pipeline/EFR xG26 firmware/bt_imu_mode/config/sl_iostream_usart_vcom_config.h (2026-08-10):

/***************************************************************************//**
 * @file
 * @brief IOSTREAM_USART Config.
 *******************************************************************************
 * # License
 * <b>Copyright 2020 Silicon Laboratories Inc. www.silabs.com</b>
 *******************************************************************************
 *
 * SPDX-License-Identifier: Zlib
 *
 * The licensor of this software is Silicon Laboratories Inc.
 *
 * This software is provided 'as-is', without any express or implied
 * warranty. In no event will the authors be held liable for any damages
 * arising from the use of this software.
 *
 * Permission is granted to anyone to use this software for any purpose,
 * including commercial applications, and to alter it and redistribute it
 * freely, subject to the following restrictions:
 *
 * 1. The origin of this software must not be misrepresented; you must not
 *    claim that you wrote the original software. If you use this software
 *    in a product, an acknowledgment in the product documentation would be
 *    appreciated but is not required.
 * 2. Altered source versions must be plainly marked as such, and must not be
 *    misrepresented as being the original software.
 * 3. This notice may not be removed or altered from any source distribution.
 *
 ******************************************************************************/

#ifndef SL_IOSTREAM_USART_VCOM_CONFIG_H
#define SL_IOSTREAM_USART_VCOM_CONFIG_H

// <<< Use Configuration Wizard in Context Menu >>>

// <h>USART settings

// <o SL_IOSTREAM_USART_VCOM_BAUDRATE> Baud rate
// <i> Default: 115200
#define SL_IOSTREAM_USART_VCOM_BAUDRATE              115200

// <o SL_IOSTREAM_USART_VCOM_PARITY> Parity mode to use
// <usartNoParity=> No Parity
// <usartEvenParity=> Even parity
// <usartOddParity=> Odd parity
// <i> Default: usartNoParity
#define SL_IOSTREAM_USART_VCOM_PARITY                usartNoParity
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

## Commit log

2026-08-09 Add VitalSense Flutter mobile dashboard app
    Implement a complete Flutter application for real-time patient vital monitoring. The app implements VitalSense Protocol v1, receiving UDP broadcasts on port 5005 from ESP32-C3 devices. Includes featu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
2026-08-09 Add background monitoring, notifications, logs & settings
    Introduce background monitoring, rich notifications, persistent logs and user settings. Adds NotificationService, BackgroundService, LogsScreen and SettingsScreen and integrates workmanager, flutter_local_notifications, shared_preferences, timezone and permission_handler (pubspec + lock updated). Wire up plugin registration, AndroidManifest permissions, and enable coreLibraryDesugaring in build.gradle. Ensure Widgets binding init in main and extend VitalSenseProvider to manage notifications, background monitoring, logging, reconnect logic and lifecycle cleanup. Also add RELEASE_NOTES for v1.0.0 and v1.1.0.
2026-08-09 Add VitalS App with backend, frontend, and UI
    Introduce a complete VitalS-App project: main controller (app.py) that orchestrates ConfigManager, BackendManager, FrontendManager and the GTK/WebKit dashboard with kiosk mode, readiness polling, logging and clean shutdown handling (including a local shutdown API). Add core managers: backend_manager (process control, logs, watchdog/restarts), frontend_manager (no-cache HTTP server), and config_manager (fixes load() to return parsed config). Add Flask-SocketIO UDP bridge (backend/udp_server.py) to translate ESP32 UDP JSON -> Socket.IO, plus admin/settings endpoints. Add React frontend (frontend/app.jsx) with 3D models, GTK UI modules (ui/login.py,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
    [app.py, app_backup.py]
2026-08-10 Hardware firmware update
    added the firmware for both boards- efr xg26 board(module 1) and esp32(module 2).
2026-08-11 Add VitalSense READMEs and project documentation
    Replace generic template README with a full VitalSense project README and add detailed per-project documentation. New files: ESP32 firmware, Synthetic dataset kit, model, vitalsense-dashboard READMEs; updated EFR xG26 firmware readme. Documents include system architecture, BLE/UDP protocol, ML model spec, ADC calibration, build/flash steps, and licenses to onboard developers and integrators.
2026-08-12 Fix security issues and add CI workflows
    - Replace hardcoded WiFi credentials in ESP32 firmware with placeholders
    - Replace hardcoded admin password in dashboard config with placeholder
    - Add .gitignore files for ESP32 firmware, EFR32 firmware, vitalsense-dashboard, vitalsense-app
    - Update root .gitignore with better patterns for venv, logs, build artifacts
    - Remove backup files from git tracking (app_backup.py, udp_server.py.bak)
    - Update projects/README.md - remove 'to be created' note for dashboard
    - Add platformio.ini for ESP32 firmware CI
    - Add GitHub Actions workflows:
    - flutter-app-ci.yml for Flutter mobile app
    - python-dashboard-ci.yml for Python GTK/WebKit dashboard
    - esp32-fi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
    [VitalSense_ESP32.ino, app_backup.py]
2026-08-12 Revert "Fix security issues and add CI workflows"
    This reverts commit c85fc4c1f4098ed6627728390f146250f4ece7fd.
    [VitalSense_ESP32.ino, app_backup.py]
2026-08-21 Add BLE Wi-Fi provisioning for ESP32 and app
    Implements end-to-end BLE Wi‑Fi provisioning. ESP32 firmware: adds a provisioning GATT service (SSID/Password/Command/Status UUIDs), staging/verification, NVS (Preferences) storage, CONNECT/STATUS/CL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
    [module1(base).stl, module1(upper).stl, module2(base).stl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]
